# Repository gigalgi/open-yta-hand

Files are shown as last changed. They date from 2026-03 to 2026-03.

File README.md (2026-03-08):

# open-yta-hand

**Underactuated anthropomorphic hand with integrated wrist — 7 DOF per finger, LSTM kinematics, impedance control, ~$8 per finger.**






---

> *Yta* — "hand" in Muisca, the language of the pre-Columbian Chibcha civilization of the Colombian highlands.

---

## Overview

Open-Yta-Hand is a monolithic anthropomorphic robotic hand. The hand is modular:
five UMoBIC fingers assembled into a palm bracket, each finger independent and
using the same tendon coupling and actuation approach. Every joint in the finger
is a UMoBIC compliant revolute unit — printed in one session, no assembly of
structural parts. The control stack runs from ArUco motion capture data collection
through LSTM-based inverse kinematics to real-time impedance control on Arduino.

```
motion_capture/ → dataset/ → lstm/ → firmware/ → hardware
                                  ↓
                          simulation/mujoco
                                  ↓
                              rl/
```

<div align="center">
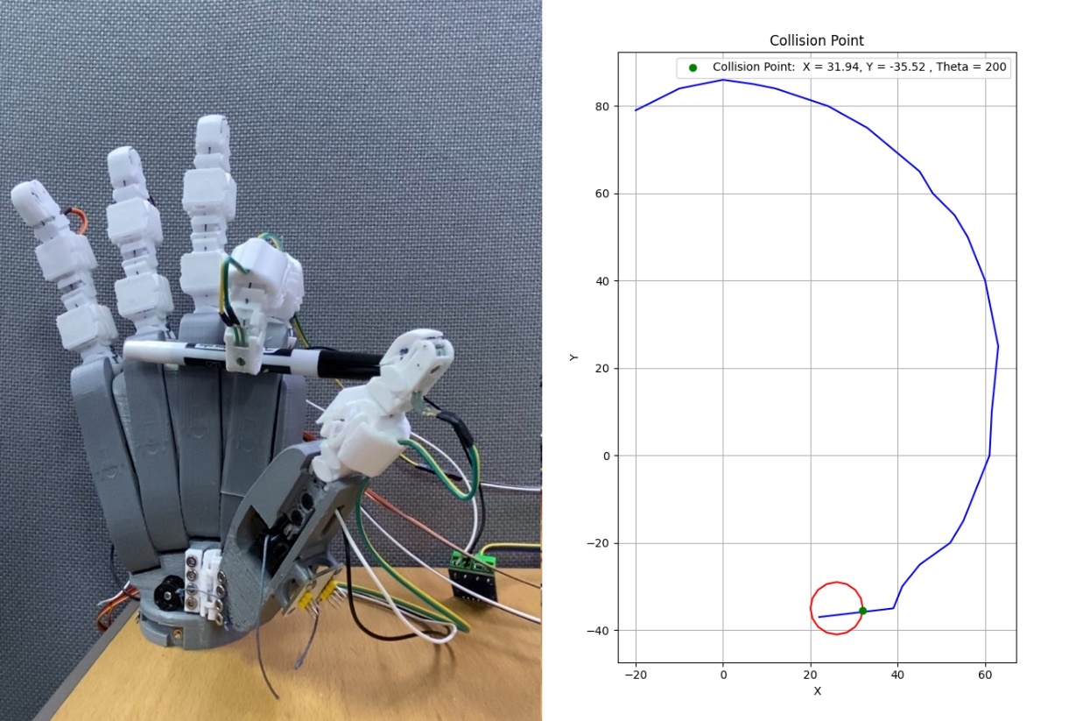
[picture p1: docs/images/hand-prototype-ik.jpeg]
Physical hand prototype
  
  <br><em>Physical prototype and computed fingertip trajectory with grasp collision point.</em>
</div>

---

## Repository Structure

```
open-yta-hand/
├── cad/
│   └── stl/
│   │    ├── arm/
│   │    │   ├── shoulder/
│   │    │   └── elbow/
│   │    ├── hand/
│   │    │   ├── finger/
│   │    │   ├── palm/
│   │    │   └── thumb/
│   │    └── wrist/
│   │
│   └── step/ full assembly
│       
│
├── motion_capture/          ArUco data collection, preprocessing
│   ├── dataset_collection.py
│   ├── marker_detection.py
│   ├── marker_creator.py
│   ├── serial_logger.py
│   ├── data_cleaning.py
│   └── data_slicing.py
│
├── dataset/                 Collected motion capture data
│   ├── finger_trajectory_dataset.csv
│   ├── train_data.csv
│   └── test_data.csv
│
├── kinematics/              Analytical and simulation models
│   ├── forward_kinematics.py
│   ├── continuum_ik.py
│   ├── optimization_ik.py
│   ├── finger_simulator.py
│   └── trajectory_simplifier.py
│
├── lstm/                    LSTM joint angle observer
│   ├── model.py
│   ├── train.py
│   ├── predict.py
│   └── weights/
│       └── lstm_inverse_kinematics.pth
│
├── simulation/
│   ├── mujoco/              MuJoCo model — exact physics, ground truth
│   │   ├── mjmodel.xml
│   │   ├── objects/pen.xml
│   │   └── meshes/
│   └── isaac_sim/           Isaac Sim simulation (in development)
│
├── rl/                      Reinforcement learning (SAC)
│   ├── env.py
│   ├── train.py
│   ├── play.py
│   ├── workspace_vis.py
│   └── weights/
│
├── firmware/
│   └── impedance_control/
│       └── impedance_control.ino
│
├── ros2_ws/                 ROS2 control package (in development)
│   └── src/umobic_finger/
│
├── docs/images/
├── requirements.txt
└── .gitignore
```

---

## Hardware

### The Finger — 208 mm, 7 DOF

Each finger is a single PETG print with all joints, pulleys, and skin modules in one session. Two motors drive the entire structure:

- **Motor 1 (JA12-N20, 1:150 + 2:1 bevel gear)** — flexion/extension via main cable routed through all phalanges
- **Motor 2 (MG90S servo)** — abduction/adduction via 90°-offset MCP joint
- **Cam-follower differential** — passively decouples DIP joint for precision tip grasps

<div align="center">
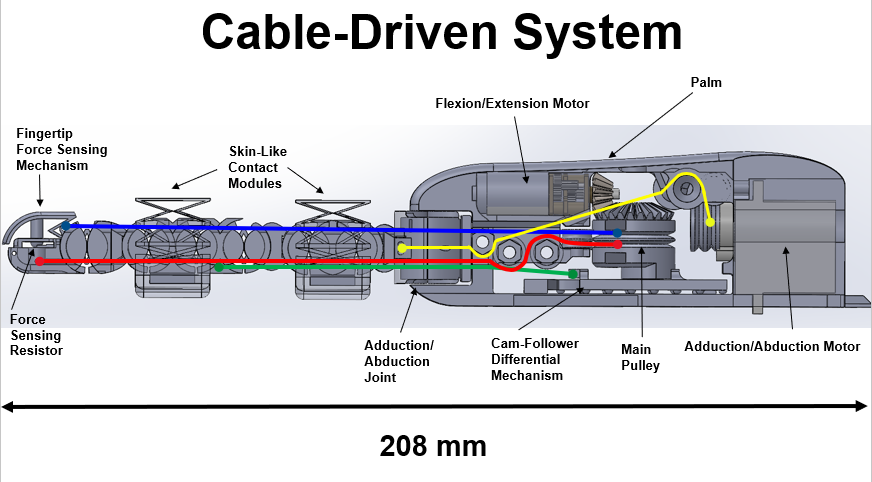
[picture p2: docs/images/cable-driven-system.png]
Cable-driven system
  
  <br><em>Internal mechanism: FSR-400 force sensing, skin modules, adduction joint, cam-follower differential, main pulley — 208 mm total.</em>
</div>

**Specs:**

| Parameter | Value |
|---|---|
| DOF per finger | 7 (6 flexion + 1 abduction) |
| Length | 208 mm |
| Weight | ~85 g |
| Cost (incl. actuators + sensors) | ~$8 USD |
| Material | PETG |
| Fabrication | Single FDM session (Creality Ender 3 V2 Neo) |
| Encoder | AS5600 magnetic (12-bit, I²C) |
| Force sensor | FSR-400 (0–10 N via fingertip transmission) |
| Microcontroller | Arduino (ATmega or equivalent) |

---

## Kinematics Pipeline

The cable-driven underactuated design couples all 6 flexion joints through a single tendon. Cable elasticity, friction, and the passive differential make the relationship between motor angle θ and fingertip position (x, y) highly nonlinear — impossible to capture analytically at high angles.

### 1. Forward Kinematics (analytical)

When the main pulley with radius r_p rotates by θ, the cable change distributes across n rolling-contact joints:

```
φᵢ = (r_p · θ) / (rᵢ · n)
```

The 2D simulator (`kinematics/finger_simulator.py`) visualizes this interactively — use arrow keys to rotate the pulley and watch all joints respond.

### 2. Continuum IK

Models the finger as a single-section continuum robot, computing bending angle and arc length from chord vector. Accurate at low angles, diverges at high angles due to unmodeled cable elasticity.

### 3. LSTM Joint Angle Observer

Selected over FNN, RNN, CNN, and Transformer after systematic comparison (see thesis Table 4.1). LSTM scored highest on temporal dependency handling, nonlinearity modeling, and robustness to noise — all critical for cable-driven compliant systems.

**Architecture:**
```
Input (x, y) → LSTM(64 hidden) → Linear → θ_motor
```

**Training:**
- Dataset: 4 runs × 2000 samples = ~8000 points
- Split: 75% train / 15% test
- Optimizer: Adam, lr=0.01, weight_decay=0.01
- Scheduler: lr × 0.5 every 10 epochs
- Epochs: 100, batch size: 32

**Results:**

| Metric | Value |
|---|---|
| Training loss | 0.6608 |
| Validation loss | 0.6884 |
| R² | **0.9998** |
| MSE | 0.6684 |
| RMSE | 0.8297 |
| MAE | 0.4291 |

---

## Motion Capture Setup

Data collection used a Logitech C270 camera, OpenCV, and ArUco markers to track fingertip (x, y, φ) while an AS5600 encoder measured pulley angle θ over serial.

<div align="center">
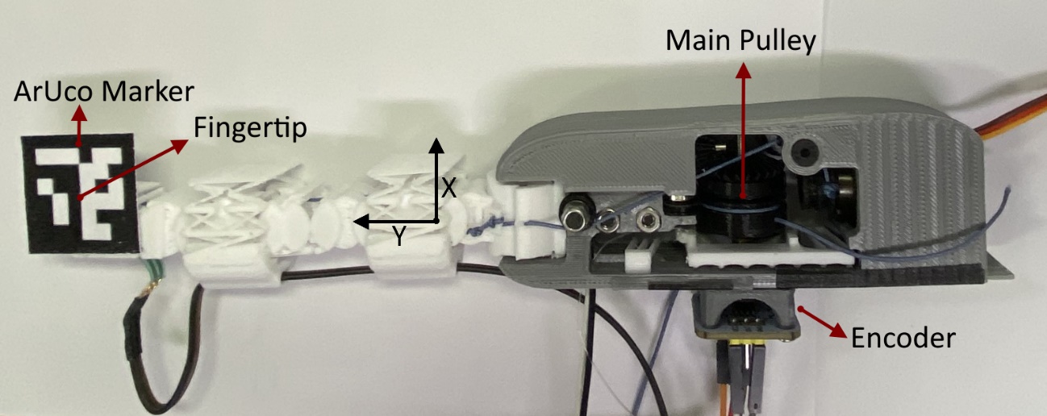
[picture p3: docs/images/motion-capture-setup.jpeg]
Motion capture setup
  
  <br><em>ArUco marker at fingertip, encoder at base. 500 samples per run × 4 runs.</em>
</div>

```bash
# 1. Print markers
python motion_capture/marker_creator.py

# 2. Collect data (camera port + Arduino serial port)
python motion_capture/dataset_collection.py

# 3. Log Arduino encoder output
python motion_capture/serial_logger.py

# 4. Clean and normalize
python motion_capture/data_cleaning.py

# 5. Split train/test
python motion_capture/data_slicing.py
```

---

## LSTM Training & Inference

```bash
# Train from scratch
cd lstm/
python train.py

# Run inference on new fingertip positions
python predict.py

# Monitor training
tensorboard --logdir logs/
```

**Quickstart inference:**
```python
from lstm.model import load_model
import torch

model = load_model("lstm/weights/lstm_inverse_kinematics.pth")

# Predict motor angle for fingertip at (31.94, -35.52)
x = torch.tensor([[[31.94, -35.52]]], dtype=torch.float32)
with torch.no_grad():
    theta = model(x).item()
print(f"θ_motor = {theta:.1f}°")  # → ~200°
```

---

## MuJoCo Simulation

The MuJoCo model represents all 9 joints with tendon equality constraints that
replicate the physical cable transmission exactly. Two position actuators drive
the structure at 500 Hz.

```bash
conda activate mujoco-env
python -m mujoco.viewer simulation/mujoco/mjmodel.xml
```

See `simulation/mujoco/README.md` for full model documentation.

---

## Reinforcement Learning

SAC policy trained entirely in MuJoCo simulation.
Observation: `[qpos(9), fingertip(3), target(3)]`.
Action: `[servo, motor]` normalized to `[-1, 1]`.

```bash
conda activate mujoco-env

# Train
python rl/train.py --steps 300000

# Watch training with viewer
python rl/train.py --steps 50000 --render

# Run trained policy
python rl/play.py --model rl/weights/best.zip

# Visualize reachable workspace
python rl/workspace_vis.py --steps 10000
```

---

## Impedance Control (Arduino)

`firmware/impedance_control/impedance_control.ino` implements a variable spring-mass-damper controller running at 100 Hz:

```
τ = K·(θ_desired − θ) + B·(−θ̇) + M·(−θ̈) − F_contact
```

**Key design decisions:**
- **Variable K and B** — stiffness halves when position error < 5°, damping reduces near zero velocity
- **Kalman filters** on velocity, acceleration, and contact force independently
- **SolidWorks-derived inertia** — M = 451.27 × 10⁻⁹ kg·m² from CAD model
- **Self-calibration on boot** — 30-sample FSR-400 offset averaging

| Parameter | Value |
|---|---|
| Stiffness K | 6.25 N/deg |
| Damping B | 2.25 N·s/deg |
| Inertia M | 451.27 × 10⁻⁹ kg·m² |
| Sample rate | 100 Hz |
| Encoder | AS5600, 12-bit |
| Force sensor | FSR-400, max 1000g |

---

## Grasping Results

Tested across 12+ object types including rigid (Rubik's cube, Pringles can), soft (sponge), and tool-shaped (marker, pliers) objects.

<div align="center">
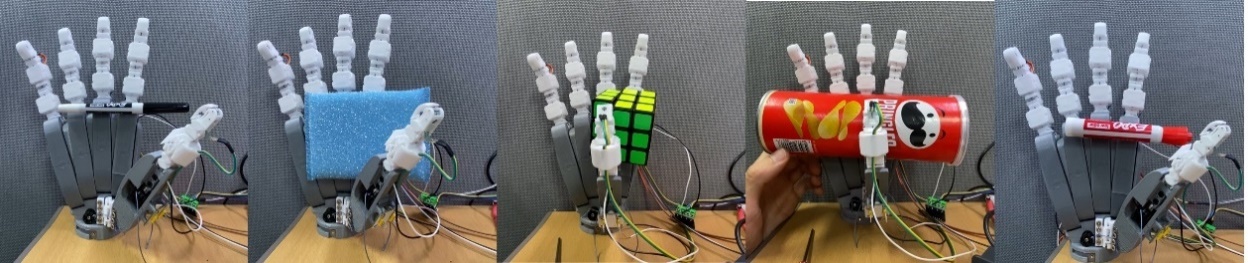
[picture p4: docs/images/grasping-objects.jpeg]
Grasping results
  
  <br><em>Underactuated grasps: marker, sponge, Rubik's cube, Pringles can, tip grasp.</em>
</div>

<div align="center">
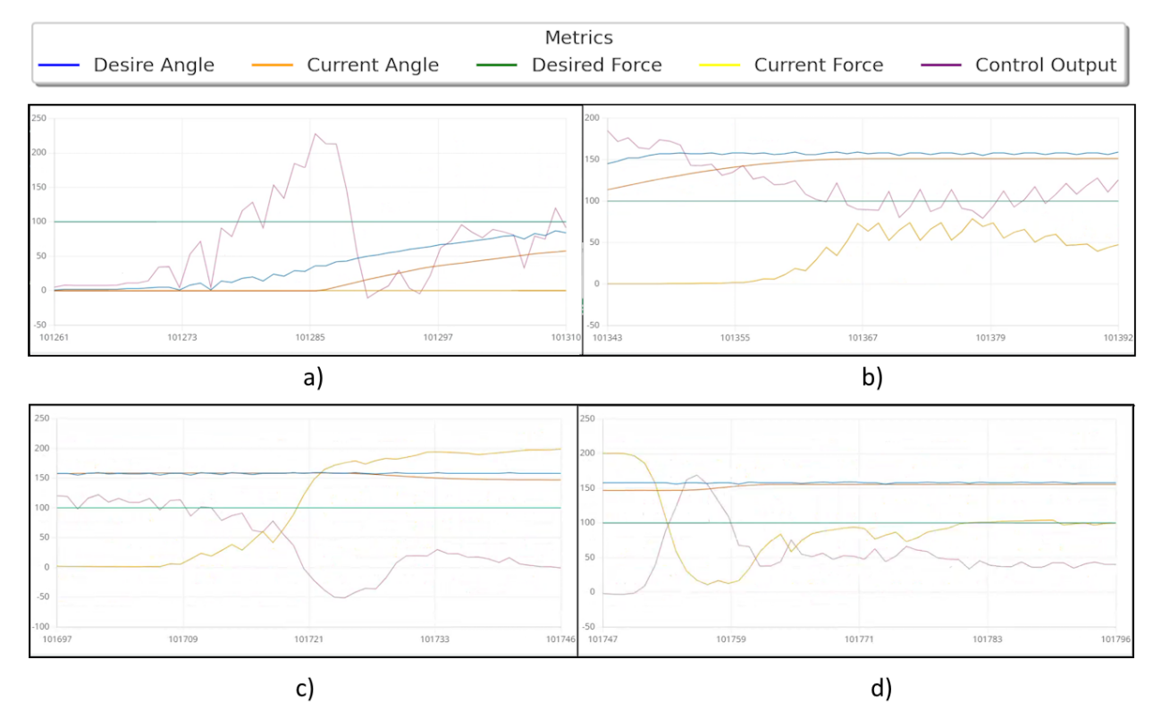
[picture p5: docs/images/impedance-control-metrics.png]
Impedance metrics
  
  <br><em>Impedance control metrics across four grasping trials.</em>
</div>

---

## 3D Printing

The `cad/stl/` folder contains STL files for the complete physical assembly:
finger, palm, thumb, wrist, shoulder and elbow.
Full mechanical context and assembly diagrams are in the thesis.

### Material

**PETG is strongly recommended over PLA.** PETG has higher elasticity which
gives more life cycles at the flexible joint layers before fatigue failure.
PLA is stiffer and will crack at the flex zones sooner under repeated actuation.

- Layer height: 0.2 mm is sufficient for all parts
- Supports: use tree-type supports — easier to remove from narrow flex zones

### Print orientation — critical

**Layer orientation is the most important parameter for this design.**
Flexible layers must be oriented so that layer lines run perpendicular to
the direction of motion. Parallel layer lines cause delamination under
repeated bending. Most parts use 2D geometry that grows vertically for
this reason. Print them standing upright as oriented in the STL files.

### Wrist — special handling required

> ⚠️ **Warning — experimental design**
>
> The wrist joint uses a 3D configuration unlike the 2D geometry of the
> finger and other joints. Correct layer orientation cannot be achieved
> for all surfaces in a single print. Parts printed as one piece have a
> higher risk of cracking at the flex zone under load.
>
> **Recommended approach:** print the wrist in two separate halves,
> keeping the critical flex surface correctly oriented in each half,
> then bond with cyanoacrylate or epoxy.

The elbow and shoulder follow the same 2D vertical geometry as the finger
and can be printed as single pieces. All arm joints should be considered
experimental — long-term fatigue behavior under repeated actuation has
not been fully characterized.

---

## In Development

**ROS2 control and simulation bridges** — architecture and implementation
are defined. MuJoCo bridge, Isaac Sim integration, and policy node are
implemented but require further debugging and testing.
See `ros2_ws/` and `simulation/isaac_sim/`.

**open-yta-hand-mk2** — a next-generation hand currently in development.
It follows the same design philosophy as the monolithic anthropomorphic hand
project and the UMoBIC finger. The mk2 builds on this foundation adding
better features for skin, force and shape sensing and more independent
degrees of freedom for easier control.

---

## Getting Started

```bash
git clone https://github.com/yourusername/open-yta-hand
cd open-yta-hand
pip install -r requirements.txt

# Interactive 2D finger simulator
python kinematics/finger_simulator.py

# MuJoCo simulation
conda activate mujoco-env
python -m mujoco.viewer simulation/mujoco/mjmodel.xml

# LSTM inference
python lstm/predict.py
```

---

## Publications

**ICCAS 2024**
> *Design of a Modular Anthropomorphic Hand with Integrated Monolithic Compliant Fingers and Wrist Joint*
> Gilberto Galvis Giraldo, Arpan Ghosh, Tae-Yong Kuc. [[Paper]](https://ieeexplore.ieee.org/document/10773068)

**Master's Thesis — SKKU 2024**
> *Monolithic Robotics with Cognitive AI: A Compliant Mechanism-Based Anthropomorphic Arm Design for Semantic Autonomous Manipulation*
> Gilberto Galvis Giraldo
> [[Full text]](https://dcollection.skku.edu/srch/srchDetail/000000181091?localeParam=en)

**Technical Report — 2023**
> *UMoBIC-Finger: A FACT-Based Compliant Revolute Joint for Monolithic Robotic Fingers*
> [[monolithic-robotics repository]](https://github.com/gigalgi/monolithic-robotics)

---

## Related Repositories

| Repository | Description |
|---|---|
| [monolithic-robotics](https://github.com/yourusername/monolithic-robotics) | Design framework — UMoBIC joint, FACT methodology, technical report |

---

## Author

**Gilberto Galvis Giraldo**
M.Sc. Electrical and Computer Engineering — Sungkyunkwan University, South Korea

---

## License

Apache License 2.0 — see [LICENSE](LICENSE) for details.

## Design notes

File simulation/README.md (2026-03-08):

# simulation/

Physics simulation files for the UMoBIC-Finger.
Two simulators, each with its own folder and model file.

```
simulation/
├── mujoco/
│   ├── mjmodel.xml        MuJoCo model — exact physics, ground truth
│   └── objects/pen.xml    pen object included by mjmodel.xml
│   └── meshes/            STL files shared by both simulators
└── isaac_sim/
    ├── finger_isaac.urdf  Isaac Sim model
    ├── isaac_play.py      standalone viewer — sliders, no ROS2
    └── isaac_bridge.py    ROS2 controlled — same topics as mujoco_bridge
```

---

## mujoco/

The ground truth model. Used by the RL training pipeline and the
ROS2 MuJoCo bridge.

`mjmodel.xml` defines:
- Exact rolling-contact joint kinematics via tendon equality constraints
- Position actuators for servo and motor (`joint_s_pos`, `joint_m_pos`)
- Contact capsules on each phalanx for pen interaction
- A `fingertip` site at the tip of the distal phalanx — used by
  `rl/env.py` and `ros2_ws/mujoco_bridge.py` to get exact fingertip
  world position without any FK computation

Run standalone (no ROS2):
```bash
python -m mujoco.viewer simulation/mujoco/mjmodel.xml
```

Run via ROS2:
```bash
ros2 launch umobic_finger sim.launch.py
```

Run via RL training:
```bash
python rl/train.py
python rl/play.py --model rl/weights/best.zip
```

---

## isaac_sim/

Isaac Sim simulation files. Two independent modes — use whichever
fits what you are doing.

### Standalone (no ROS2)

Quick visual testing. No build step. Just run.

```bash
python simulation/isaac_sim/isaac_play.py
```

A GUI panel opens with two sliders:

| Slider | Range | Effect |
|---|---|---|
| Servo | -0.3 to 0.3 rad | Abduction — side to side |
| Motor | -0.3 to 3.14 rad | Flexion — open to closed |

### ROS2 controlled

Isaac Sim runs the physics. All ROS2 nodes connect unchanged via
Isaac Sim's built-in ROS2 bridge extension.

One-time setup:
```
Isaac Sim → Window → Extensions → search "ROS2 Bridge" → enable + autoload
```

Run:
```bash
# Terminal 1
python simulation/isaac_sim/isaac_bridge.py

# Terminal 2 — identical to MuJoCo workflow
ros2 run umobic_finger finger_teleop.py
ros2 param set /finger_teleop motor 1.5
```

`finger_teleop.py` and `policy_node.py` work with both bridges.
The ROS2 nodes cannot tell which simulator is running.

---

## Why two simulators

| | MuJoCo | Isaac Sim |
|---|---|---|
| Model file | `mjmodel.xml` | `finger_isaac.urdf` |
| Physics | MuJoCo (exact tendons) | PhysX |
| Fingertip position | `<site>` tag | `fingertip_site` fixed link + USD FK |
| Mimic joints | tendon equality constraints | applied manually in Python |
| ROS2 bridge | `mujoco_bridge.py` (in ros2_ws) | `isaac_bridge.py` (here) |
| Use for | RL training, full pipeline, hardware prep | visual testing, demos |
| Requires | any machine | Isaac Sim + RTX GPU |

---

## Model files are not interchangeable

Each simulator has its own model file optimised for its own format
and capabilities. They share the same STL geometry from `meshes/`
but are otherwise independent.

```
mjmodel.xml           → loaded only by MuJoCo
finger_isaac.urdf     → loaded only by Isaac Sim
ros2_ws/urdf/finger.urdf  → loaded only by RViz / robot_state_publisher
```

Ground truth kinematics always live in `mjmodel.xml`.
The URDF files are approximations suitable for visualization.

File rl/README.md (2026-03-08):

# UMoBIC-Finger — RL Training (`rl/`)

Reinforcement learning pipeline for training a fingertip positioning policy
on the UMoBIC-Finger **in simulation only**. No hardware connection needed.

---

## Position in the full system

```
rl/train.py          trains the policy in MuJoCo simulation
      ↓
rl/play.py           interactive: type a target, finger moves and holds
      ↓
(future) pipeline.py → predict.py → SerialBridge → Arduino
```

The RL policy learns the relationship between **servo + motor commands** and
**fingertip position in 3D space**. Once trained, give it any reachable target
coordinate and it drives the finger there and holds that position.

---

## File structure

```
rl/
├── config.py            All hyperparameters and paths — edit here only
├── env.py               Gymnasium environment wrapping mjmodel.xml
├── train.py             SAC training + checkpointing + optional live viewer
├── play.py              Interactive viewer: type target → finger moves → holds
├── workspace_vis.py     3D plot of the real reachable fingertip workspace
├── requirements.txt     Python dependencies
├── weights/             Saved checkpoints (created on first run)
└── logs/                TensorBoard logs (created on first run)
```

---

## Quick start

### 1. Install dependencies

```bash
pip install -r rl/requirements.txt
```

### 2. Train

```bash
# Headless — full speed (recommended for full runs)
python rl/train.py

# With live MuJoCo viewer — ~30% slower, use for debugging behavior
python rl/train.py --render

# Short debug run — watch ~15 seconds of sim, then stop
python rl/train.py --render --steps 5000

# Resume from checkpoint
python rl/train.py --resume rl/weights/ckpt_100000.zip

# Custom step budget
python rl/train.py --steps 500000
```

Monitor training in a second terminal:

```bash
tensorboard --logdir rl/logs/SAC_1
```

The best model by mean reward is always saved at `rl/weights/best.zip`.

#### What `--steps` means

Each step = one action applied to the simulation (5 physics substeps at 0.002s each = 0.01s of simulated time).

```
5,000 steps  ≈  50 s simulated  ≈  ~2 min wall-clock  (with --render)
50,000 steps ≈   8 min simulated ≈  ~15 min wall-clock  (with --render)
300,000 steps ≈  50 min simulated ≈  ~30 min wall-clock  (headless)
```

Each episode is 300 steps (3 seconds of sim). So 300k steps ≈ 1,000 episodes.

#### Recommended debug workflow

```bash
# 1. Confirm viewer opens and finger moves
python rl/train.py --render --steps 5000

# 2. Watch early learning — is reward going up?
python rl/train.py --render --steps 50000

# 3. Full training, no viewer, full speed
python rl/train.py --steps 300000
```

### 3. Visualize the workspace

Before or after training, see where the fingertip can actually reach:

```bash
# Run from anywhere — script resolves its own path
python rl/workspace_vis.py
python rl/workspace_vis.py --steps 10000     # denser plot
python rl/workspace_vis.py --color-by z      # color by height
python rl/workspace_vis.py --color-by time   # color by sweep order
```

The plot shows the real reachable arc plus the pen center and grasp contact
point from `grasp_point_generator.py` — so you can verify the pen sits
inside the fingertip workspace.

#### Why workspace_vis.py lives in `rl/` not `kinematics/`

The workspace shown is the **actual fingertip arc produced by MuJoCo** —
computed by running random actions through `FingerEnv`, not from the
kinematic equations. It is the workspace the RL policy trains on.
It belongs next to the thing it describes. The script uses
`Path(__file__).resolve().parent` to always find `env.py` and `config.py`
regardless of which folder you run it from.

### 4. Play interactively

```bash
python rl/play.py --model rl/weights/best.zip
```

The MuJoCo 3D viewer opens. Type a fingertip target in meters — the finger
moves to that position and **holds it** until you type a new target.
No auto-reset loop.

```
Waiting for target (finger is at home position)...

> 0.022 -0.035 0.100       ← set target (x y z in meters)
  Moving to target...
  dist=28.4 mm  tip=(18.1, -31.2, 96.4) mm
  dist=9.7 mm   tip=(20.8, -33.8, 99.1) mm
  dist=2.1 mm   tip=(21.9, -35.0, 100.1) mm
  Reached! dist=2.1 mm -- holding.

> r                         ← random target from real workspace
> q                         ← quit
```

**Hold behavior:** once the finger reaches the target (dist < 5 mm) or
times out (300 steps), the last motor commands are frozen — the finger
stays in position. Only a new target restarts the policy.

---

## Algorithm — SAC

SAC (Soft Actor-Critic) was chosen over PPO for this system because:

| Criterion | PPO | **SAC** |
|---|---|---|
| Sample efficiency | Low (on-policy) | **High (replay buffer)** |
| Continuous 2-DOF actions | OK | **Excellent** |
| Nonlinear tendon dynamics | Struggles | **Handles well** |
| Training without GPU | Slow | **Faster** |

All hyperparameters with rationale are in `config.py`.

---

## Observation and action spaces

### Observation (15 values)

| Index | Meaning | Unit |
|---|---|---|
| 0–8 | Joint positions: servo, motor, abd, prx×2, int×3, dis | rad |
| 9–11  | Fingertip world position (x, y, z) via `fingertip` site | m |
| 12–14 | Target position (x, y, z) | m |

The fingertip position is tracked via a MuJoCo `<site>` named `fingertip`
placed at the tip of the distal phalanx in `mjmodel.xml`. This is more
accurate than body origin (`xpos`) which points to the joint center.

### Action (2 values)

| Index | Actuator | Normalized | Real range |
|---|---|---|---|
| 0 | `joint_s_pos` — MG90S servo | [-1, 1] | [-0.3, 0.3] rad |
| 1 | `joint_m_pos` — JA12-N20 motor | [-1, 1] | [-0.3, 3.14] rad |

The 7 passive phalanx joints (prx×2, int×3, dis, abd) are **not commanded**.
They follow `joint_motor` automatically via the tendon equality constraints
in `mjmodel.xml`.

---

## Reward

Dense, minimal, interpretable:

```
reward = -distance(fingertip, target)     always on (meters)
       + 1.0                              bonus when dist < 5 mm
```

A random policy scores around **−19**. A well-trained policy scores near **−9**
at 100k steps and approaches **0** by 300k steps.

---

## Why targets are sampled from the real workspace

This is the most important design decision in `env.py`.

The finger is **underactuated** — 2 actuators drive 9 joints through tendons.
Its reachable workspace is a **thin arc in 3D**, not a rectangular bounding box.
If targets were sampled from a box, most would fall outside the arc and the
policy could never reach them. Reward would never improve and training would diverge.

**Solution (in `env.reset()`):**

```
1. Reset sim to home position
2. Run 40 random actions — record where the fingertip actually goes
3. Pick one of those visited positions as the target
   (+ 1 mm Gaussian noise for variety)
4. Reset sim to home again — episode starts from neutral
```

Step 4 is critical. Without the second reset, the episode would start from
wherever the random rollout left the finger — not from home.

Every target is reachable by construction. Use `workspace_vis.py` to see
the shape of this workspace before training.

---

## Key design decisions

**VecNormalize** — Observations are normalized online during training because
`qpos` (rad), `site_xpos` (m), and target (m) live on different scales.
Normalizer stats are saved alongside the model as `*_vecnorm.pkl`.
**Always load both files together** — the model without its normalizer
performs poorly.

**`mujoco.viewer` must be imported explicitly** — `import mujoco` does not
auto-load the viewer submodule. `env.py` imports `import mujoco.viewer`
explicitly. If you see `AttributeError: module 'mujoco' has no attribute 'viewer'`
this import is missing.

**Single callback** — `LogAndSaveCallback` handles logging, checkpointing,
and best-model tracking in one place.

**`set_target()`** — `env.py` exposes this method so `play.py` can inject
new targets at runtime without resetting the episode.

---

## TensorBoard metrics

| Metric | Meaning |
|---|---|
| `eval/mean_reward`  | Mean episode reward (last 50 episodes) |
| `eval/mean_dist_mm` | Mean fingertip–target distance in mm |
| `rollout/ep_rew_mean` | SB3 native episode reward |
| `rollout/ep_len_mean` | Mean episode length (steps) |

Reading the plots:
- `mean_reward` rising from −19 toward 0 = **training is working**
- `mean_dist_mm` falling from ~55 mm toward 5 mm = **finger getting closer**
- S-curve shape on reward = **normal SAC learning curve**
- `ep_len_mean` flat at 300 = finger hasn't converged yet (still exploring)

---

## Changing the workspace

To see where the fingertip actually goes, run:

```bash
python rl/workspace_vis.py --steps 10000
```

Targets are always sampled from the **real reachable arc** (not a config box)
so you do not need to tune `target_x_range` etc. Those config values are
kept as documentation of the approximate workspace bounds but are not used
for sampling.

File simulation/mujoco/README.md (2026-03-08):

# simulation/mujoco/

MuJoCo simulation of the UMoBIC-Finger.

```
mujoco/
├── mjmodel.xml        main model file
├── objects/pen.xml    pen object included by mjmodel.xml
└── meshes/            STL files for all finger links
```

---

## Run standalone

```bash
conda activate mujoco-env
python -m mujoco.viewer simulation/mujoco/mjmodel.xml
```

The viewer opens with the finger at home position.
Click and drag to rotate. Scroll to zoom.
Double-click a body to select it and see its properties.

---

## What mjmodel.xml defines

**Kinematics** — the finger has 2 actuated inputs and 9 joints.
The 7 phalanx joints are coupled to servo and motor via tendon
equality constraints. These are exact rolling-contact kinematics,
not the linear approximation used in the URDF files.

**Actuators** — two position actuators with gain kp = 500:
- `joint_s_pos` — drives `joint_servo` (abduction, MG90S)
- `joint_m_pos` — drives `joint_motor` (flexion, JA12-N20)

**Fingertip site** — a site named `fingertip` is attached to the
distal phalanx at `pos="0 0 -0.012"`. MuJoCo updates its world
position every physics step. Used by the RL environment and the
ROS2 bridge to get exact fingertip position without any FK computation.

**Physics** — timestep 0.002 s (500 Hz). Damping and stiffness tuned
for stable position control at the actuator gains used.

---

## Actuator ranges

| Actuator | Joint | Range | Physical meaning |
|---|---|---|---|
| `joint_s_pos` | `joint_servo` | -0.3 to 0.3 rad | Abduction L/R |
| `joint_m_pos` | `joint_motor` | -0.3 to 3.14 rad | Open to fully closed |

---

## Tendon gear ratios

MuJoCo enforces these via equality constraints every physics step:

```
joint0_abd  =  0.98   × servo
joint1_prx  =  0.2222 × motor
joint2_prx  =  0.2222 × motor
joint3_int  =  0.2222 × motor
joint4_int  =  0.2222 × motor
joint5_int  = -0.2222 × motor   (cam-follower reversal)
joint6_dis  =  0.5333 × motor
```

---

## Used by

```
rl/env.py              loads mjmodel.xml directly for RL training
rl/train.py            trains SAC policy against this model
rl/play.py             runs trained policy in the viewer
ros2_ws/mujoco_bridge  loads mjmodel.xml for ROS2 control
```

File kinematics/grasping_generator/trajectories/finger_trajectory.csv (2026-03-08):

X | Y
-20.0 | 79.0
-19.85 | 79.08
-19.7 | 79.15
-19.55 | 79.23
-19.4 | 79.3
-19.25 | 79.38
-19.1 | 79.45
-18.95 | 79.53
-18.8 | 79.6
-18.65 | 79.68
-18.5 | 79.75
-18.35 | 79.83
-18.2 | 79.9
-18.05 | 79.98
-17.9 | 80.05
-17.75 | 80.13
-17.6 | 80.2
-17.45 | 80.28
-17.3 | 80.35
-17.15 | 80.43
-17.0 | 80.5
-16.85 | 80.58
-16.7 | 80.65
-16.55 | 80.73
-16.4 | 80.8
-16.25 | 80.88
-16.1 | 80.95
-15.95 | 81.03
-15.8 | 81.1
-15.65 | 81.18
-15.5 | 81.25
-15.35 | 81.33
-15.2 | 81.4
-15.05 | 81.48
-14.9 | 81.55
-14.75 | 81.63
-14.6 | 81.7
-14.45 | 81.78
-14.3 | 81.85
-14.15 | 81.93
-14.0 | 82.0
-13.85 | 82.08
-13.7 | 82.15
-13.55 | 82.23
-13.4 | 82.3
-13.25 | 82.38
-13.1 | 82.45
-12.95 | 82.53
-12.8 | 82.6
-12.65 | 82.68
-12.5 | 82.75
-12.35 | 82.83
-12.2 | 82.9
-12.05 | 82.98
-11.9 | 83.05
-11.75 | 83.13
-11.6 | 83.2
-11.45 | 83.28
-11.3 | 83.35
-11.15 | 83.43
-11.0 | 83.5
-10.85 | 83.58
-10.7 | 83.65
-10.55 | 83.73
-10.4 | 83.8
-10.25 | 83.88
-10.1 | 83.95
-9.97 | 84.01
-9.9 | 84.02
-9.82 | 84.04
-9.75 | 84.05
-9.67 | 84.07
-9.6 | 84.08
-9.52 | 84.1
-9.45 | 84.11
-9.37 | 84.13
-9.3 | 84.14
-9.22 | 84.16
-9.15 | 84.17
-9.07 | 84.19
-9.0 | 84.2
-8.92 | 84.22
-8.85 | 84.23
-8.77 | 84.25
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

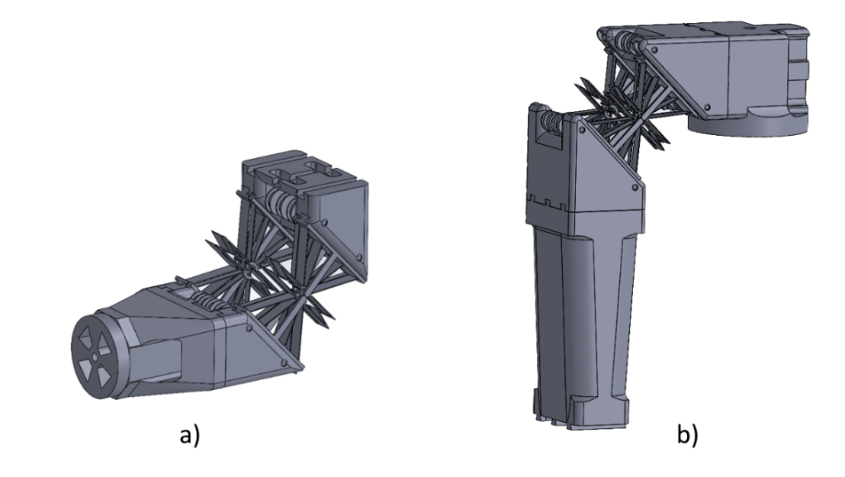
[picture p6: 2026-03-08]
docs/images/wrist-cad.png

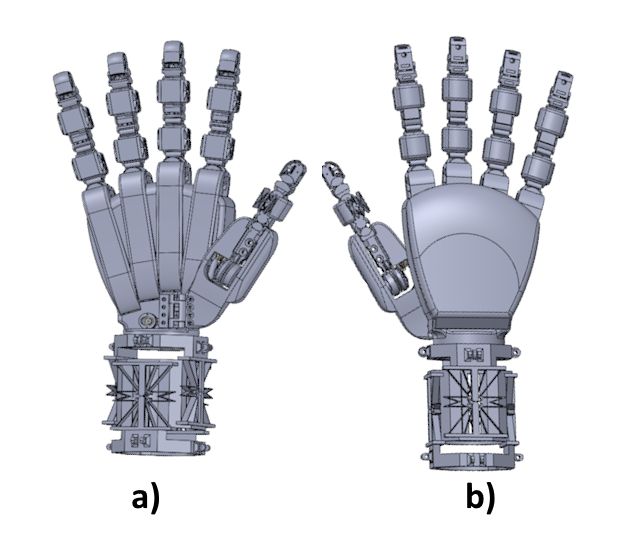
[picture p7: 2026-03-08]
docs/images/hand-cad.png

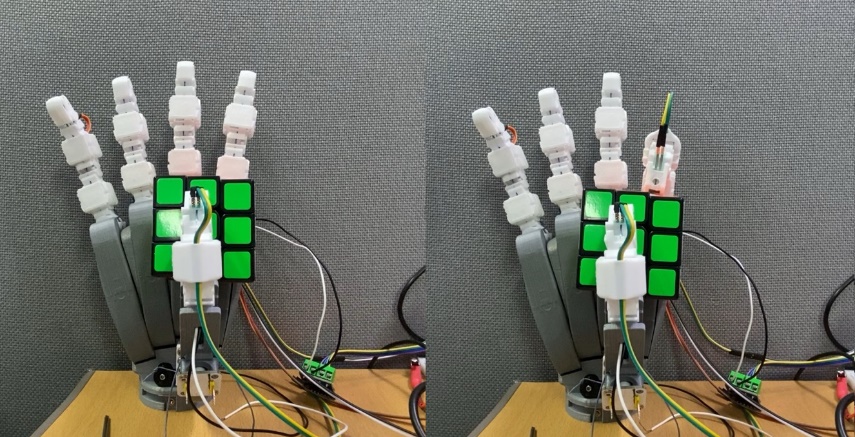
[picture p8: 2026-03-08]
docs/images/impedance-grasping.jpeg

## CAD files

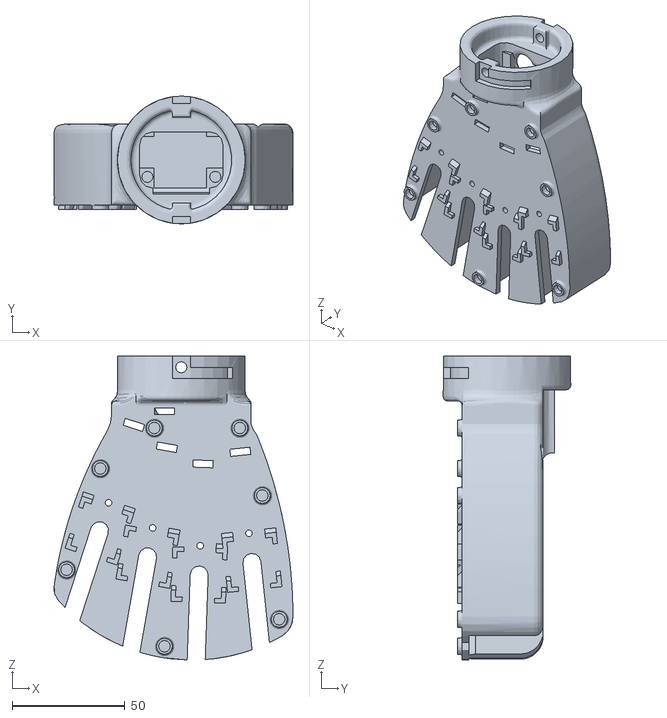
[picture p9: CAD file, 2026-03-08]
cad/stl/hand/palm/hand-main-module.STL
106.2 x 56.8 x 135.1

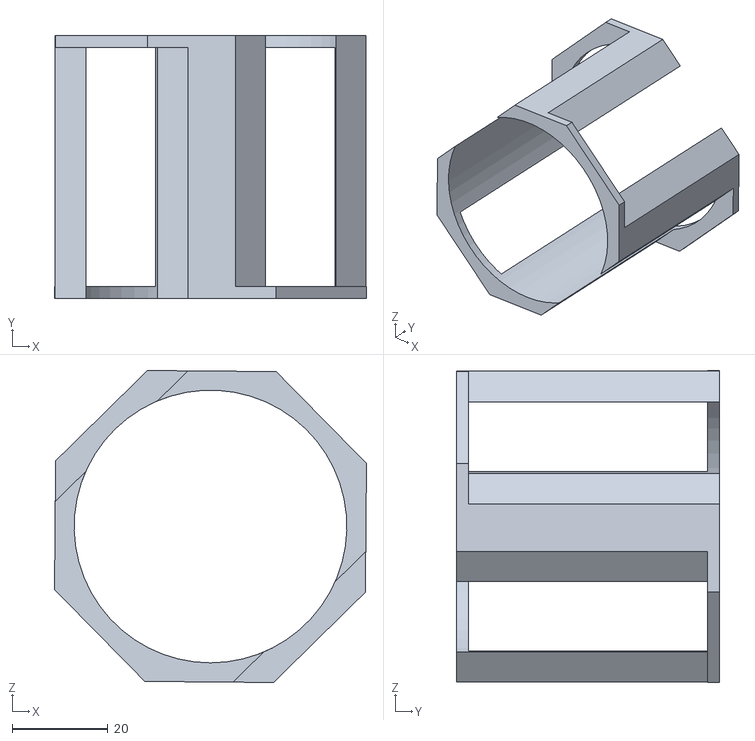
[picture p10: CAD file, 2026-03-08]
cad/stl/wrist/wrist - wrist-main-1-1.STL
65.2 x 55.0 x 65.2

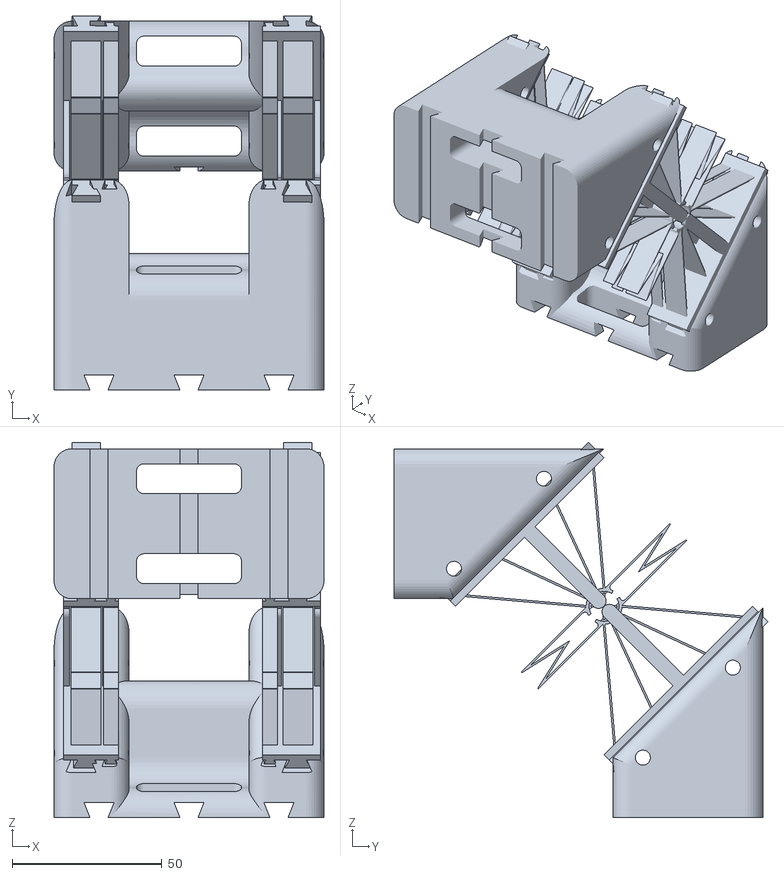
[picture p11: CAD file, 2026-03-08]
cad/stl/arm/elbow/elbow.STL
90.0 x 124.7 x 125.1

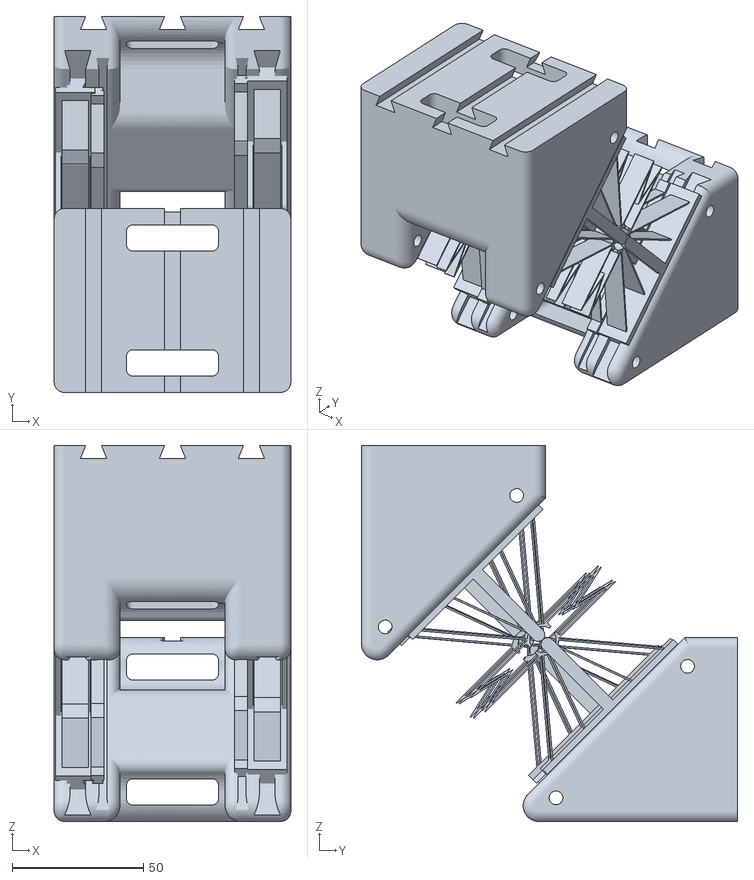
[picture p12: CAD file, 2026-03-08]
cad/stl/arm/shoulder/shoulder.STL
90.0 x 143.0 x 143.0

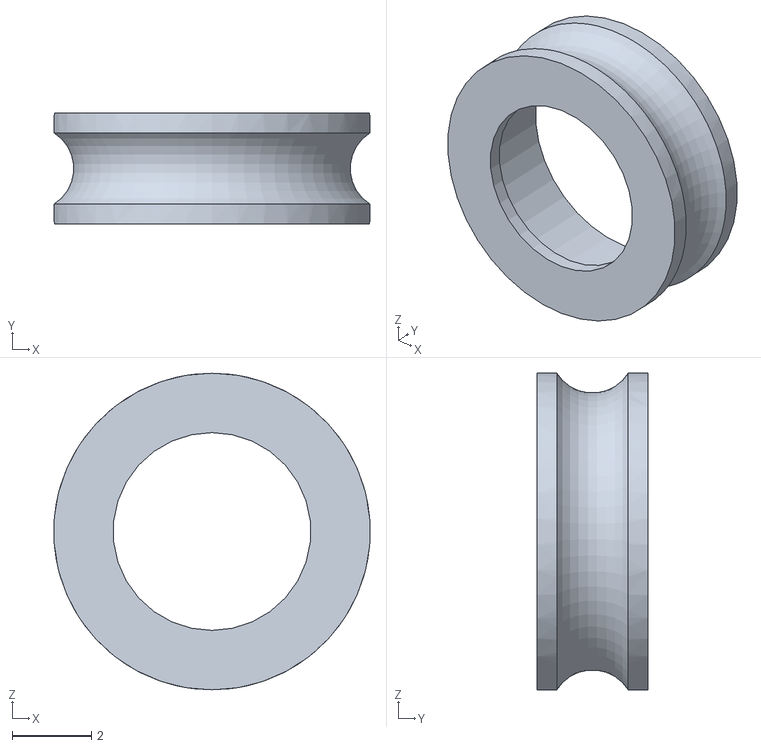
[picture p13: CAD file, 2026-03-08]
cad/stl/hand/finger/pulley-mini.STL
7.99 x 2.80 x 8.00

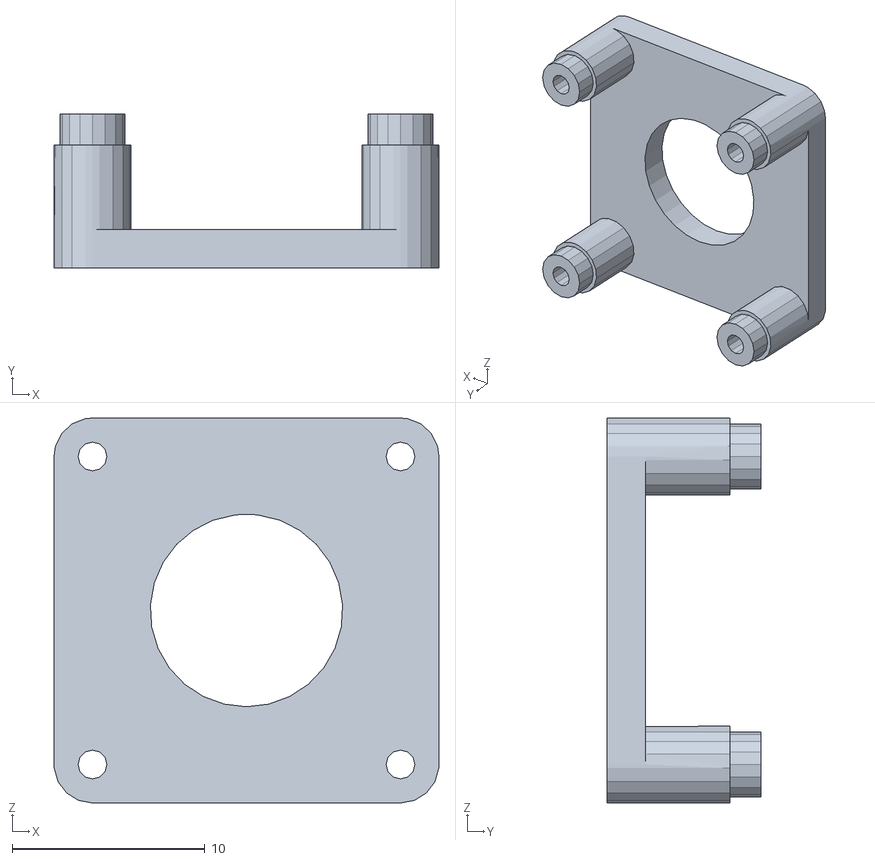
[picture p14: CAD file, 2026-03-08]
cad/stl/hand/thumb/encoder_support-1.STL
20.0 x 8.00 x 20.0

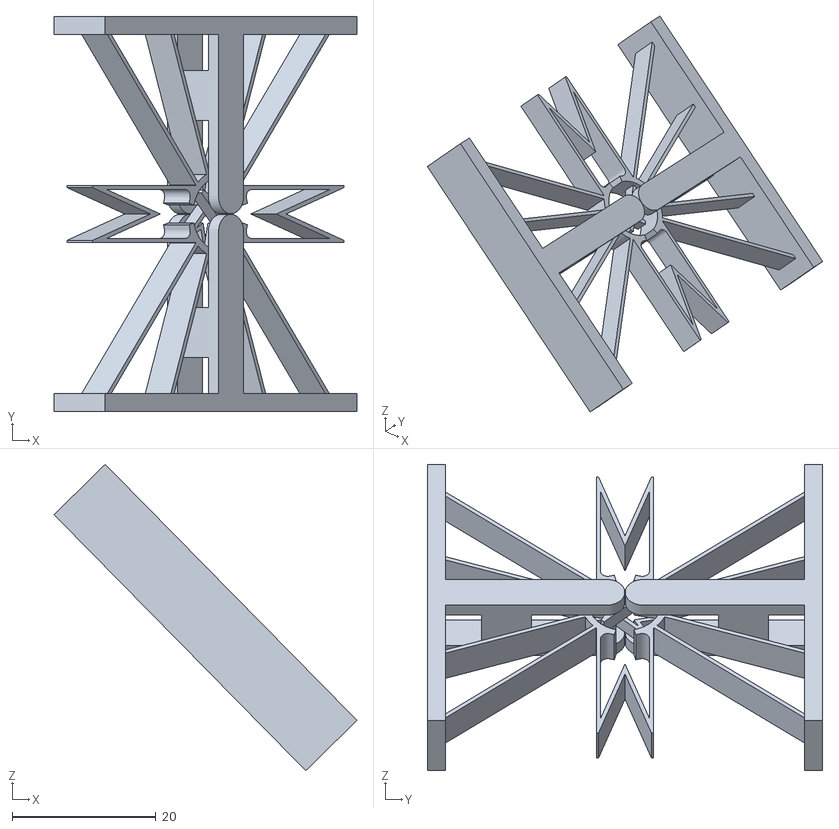
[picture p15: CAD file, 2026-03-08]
cad/stl/wrist/wrist - Part14-5mm-3.STL
42.2 x 55.0 x 42.7

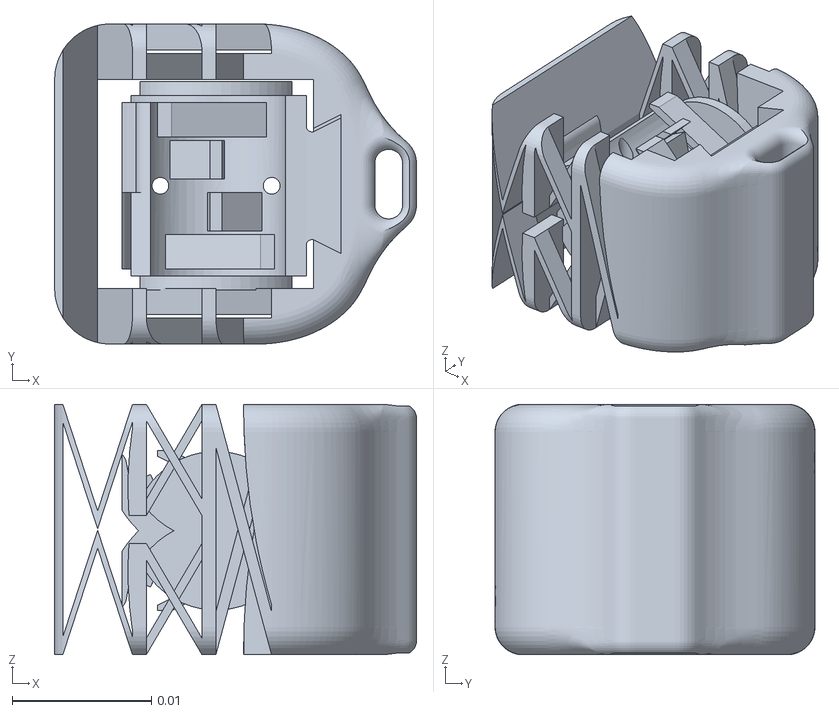
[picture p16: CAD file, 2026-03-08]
simulation/mujoco/meshes/phalanx_link2_int.STL
0.026 x 0.023 x 0.018

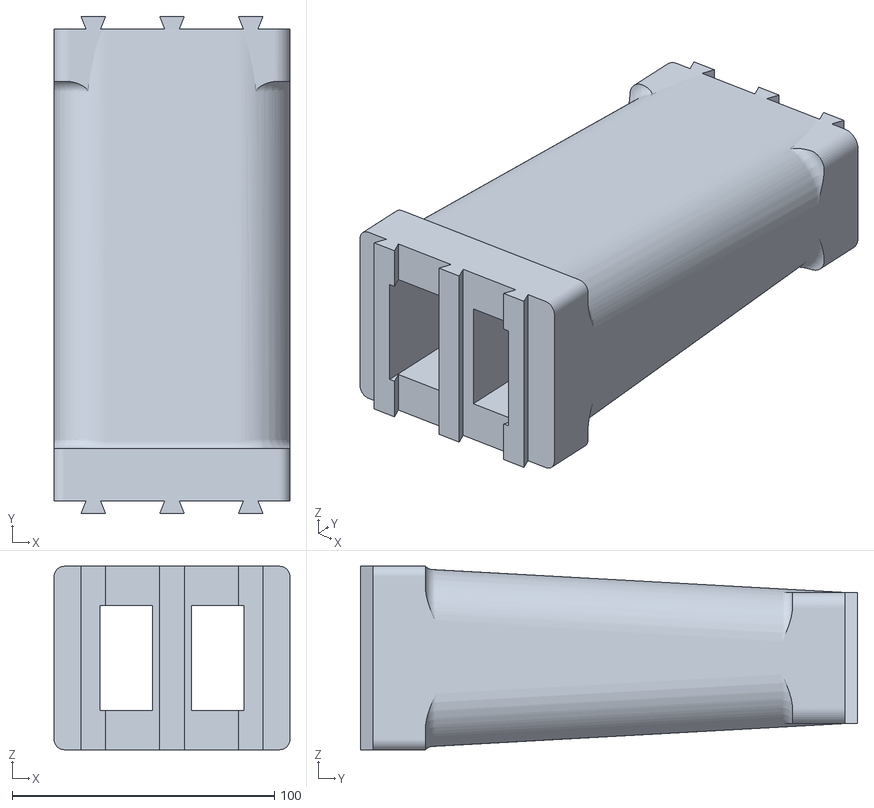
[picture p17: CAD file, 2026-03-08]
cad/stl/arm/elbow/humero.STL
90.0 x 189.6 x 70.0

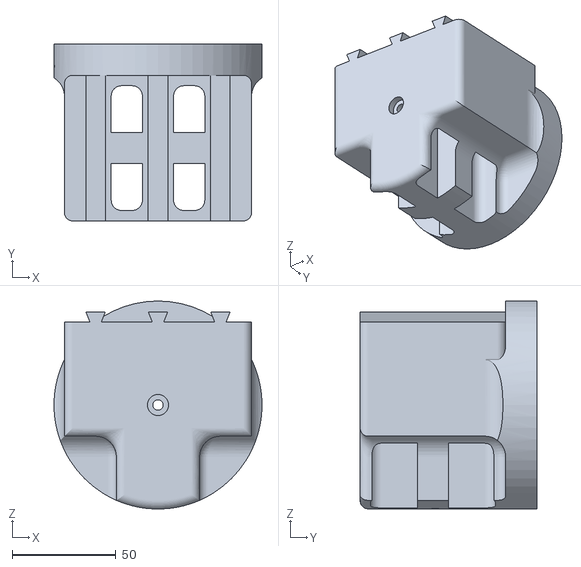
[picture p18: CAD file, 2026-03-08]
cad/stl/arm/shoulder/shoulder_rot.STL
100.0 x 85.0 x 100.0

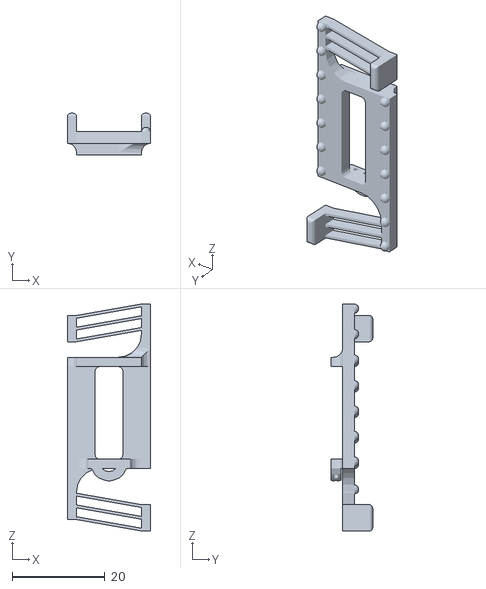
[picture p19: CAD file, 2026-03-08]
cad/stl/hand/finger/cam-follower-2.STL
18.0 x 9.00 x 49.0

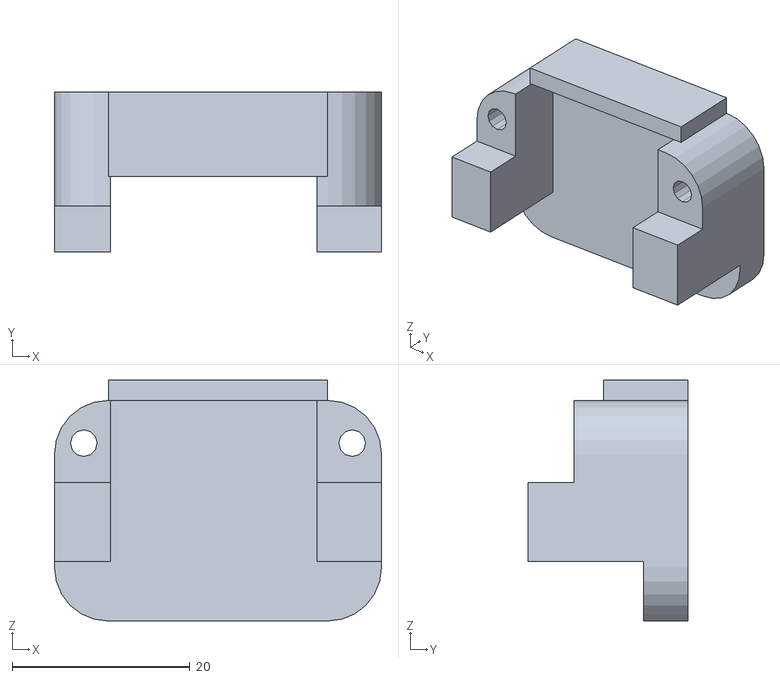
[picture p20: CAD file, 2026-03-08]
cad/stl/hand/palm/servo_palm_support.STL
36.8 x 18.0 x 27.1

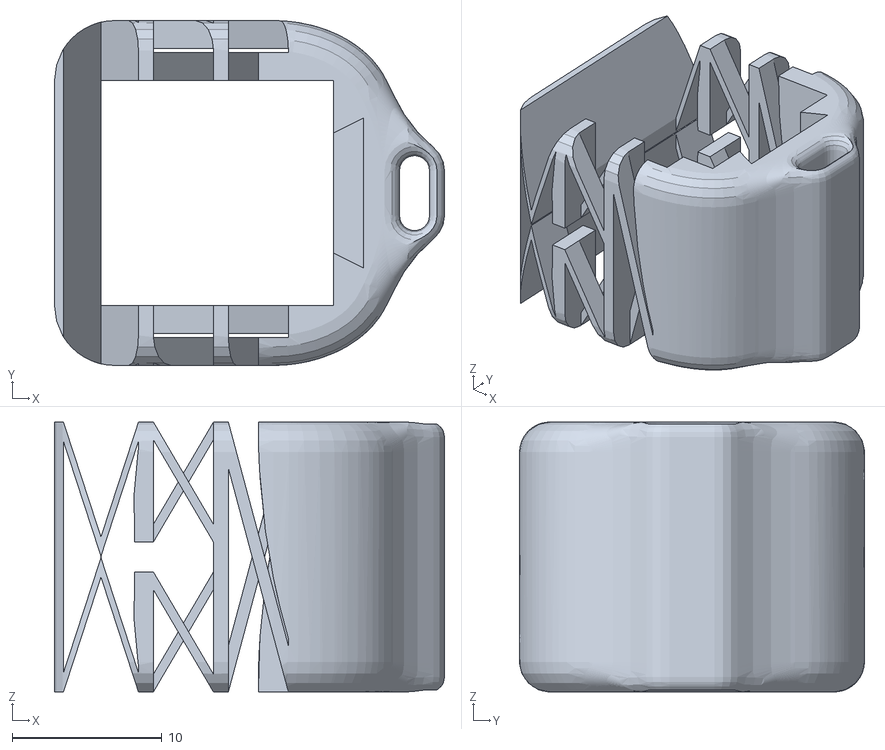
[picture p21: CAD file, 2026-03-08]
cad/stl/hand/thumb/skin8.STL
26.0 x 23.0 x 18.0

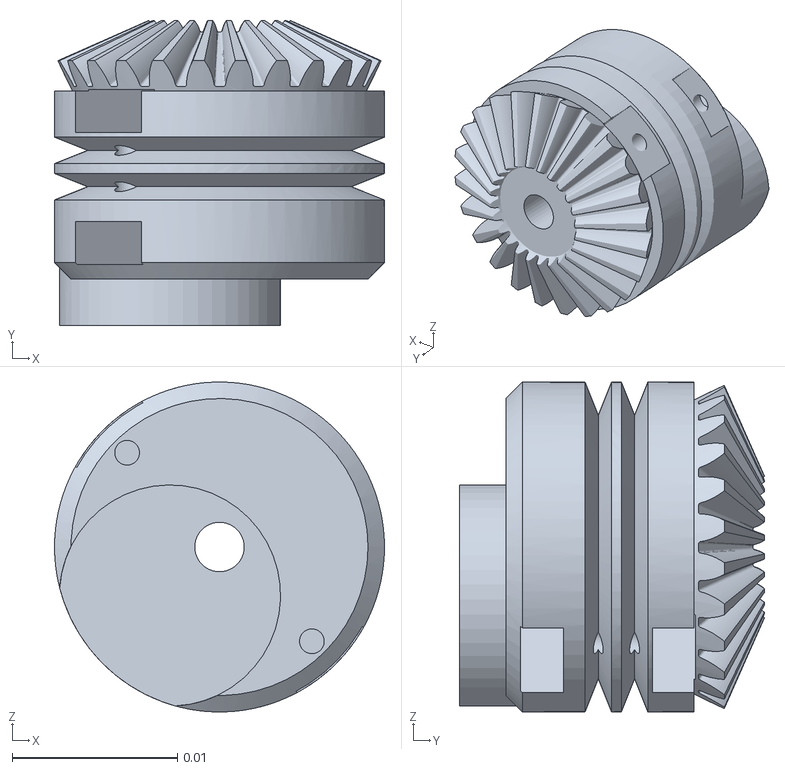
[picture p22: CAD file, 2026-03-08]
simulation/mujoco/meshes/motor_pulley_link.STL
0.02 x 0.0185 x 0.02

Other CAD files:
cad/stl/wrist/wrist - Part14-5mm-2.STL
cad/stl/hand/finger/monolithic_finger.STL
cad/stl/hand/thumb/monolithic_finger_thumb.STL
simulation/mujoco/meshes/palm_link.STL
cad/stl/hand/finger/bavel_gear_pinion.STL
cad/stl/hand/finger/bavel_gear_pulley.STL
cad/stl/hand/finger/finger-palm-module.STL
cad/stl/hand/finger/monolithic_finger_base.STL
cad/stl/hand/finger/pulley-1S.STL
cad/stl/hand/thumb/bavel_gear_pinion.STL
cad/stl/hand/thumb/bavel_gear_pulley_thumb.STL
cad/stl/hand/thumb/thumb-palm.STL
cad/stl/hand/thumb/thumb_opposable_joint.STL
cad/stl/wrist/radi_cubit.STL
cad/stl/wrist/wrist - Part14-5mm-1.STL
cad/stl/wrist/wrist - Part14-5mm-4.STL
cad/stl/wrist/wrist - wrist-support-1-1.STL
cad/stl/wrist/wrist - wrist-support-1-2.STL
cad/stl/wrist/wrist.STL
simulation/mujoco/meshes/phalanx1_link1_abd.STL
simulation/mujoco/meshes/phalanx1_link2_prx.STL
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

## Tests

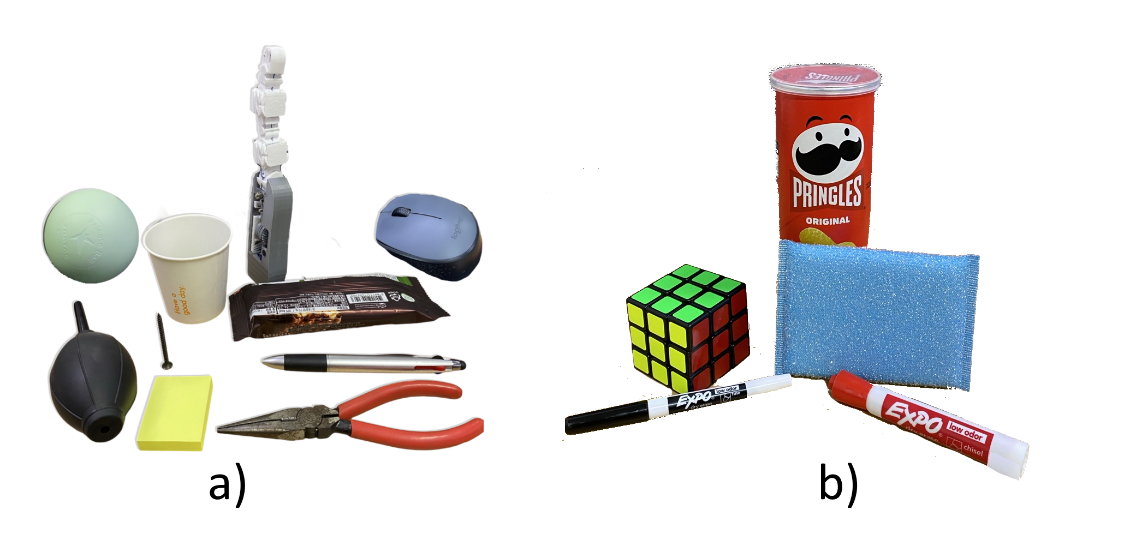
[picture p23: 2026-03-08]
docs/images/test-objects.png

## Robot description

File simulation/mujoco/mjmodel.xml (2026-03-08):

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
<mujoco model="finger_mujoco">

  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
  <compiler angle="radian" meshdir="meshes/" texturedir="texture/"/>

  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
  <option timestep="0.002" iterations="100" apirate="50"/>

  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
  <size njmax="600" nconmax="150" nstack="300000"/>

  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
  <default>
    <joint limited="true" damping="1" frictionloss="0.01" armature=".01"/>
    <position ctrllimited="true" kp="1"/>
  </default>

  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

  <worldbody>
    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
    <light pos="0 0 .6"/>
    <camera name="closeup" pos="0 -.1 .07" xyaxes="1 0 0 0 1 2"/>

    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
    <body name="servo_pulley_link" pos="0.00010005 -0.0199 0.038" quat="0.692275 0.692277 0.144062 0.144061">
      <inertial pos="0 0.0033461 0" quat="0.663108 -0.245537 -0.245537 0.663108" mass="0.00064912" diaginertia="1.7526e-08 1.17082e-08 1.12928e-08"/>
      <joint name="joint_servo" type="hinge" pos="0 0 0" axis="0 1 0" range="-1 1"/>
      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
    </body>

    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
    <body name="motor_pulley_link" pos="0 -0.0065 0.0575" quat="-3.67314e-06 0.999981 -2.2658e-08 -0.00616846">
      <inertial pos="-0.00028931 0.0095592 -0.00028355" quat="0.577387 0.126641 0.408197 0.695674" mass="0.0053624" diaginertia="2.60047e-07 2.57854e-07 2.16879e-07"/>
      <joint name="joint_motor" type="hinge" pos="0 0 0" axis="0 1 0" range="-3.14 3.14"/>
      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
    </body>

    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
    <body name="phalanx1_link1_abd" pos="0.00025 -0.0054079 0.10695" quat="1.34924e-11 -3.67321e-06 1 -3.67321e-06">
      <inertial pos="-5.9722e-05 -0.0084809 -0.0081966" quat="0.0381308 0.680879 -0.0123433 0.731298" mass="0.0025141" diaginertia="9.34887e-08 6.5377e-08 5.99283e-08"/>
      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
      <joint name="joint0_abd" type="hinge" pos="0 0 0" axis="0 1 0" range="-0.7 0.7"/>
      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
      <body name="phalanx_link1_prx" pos="0 -0.0085921 -0.01705" quat="0.707105 0 0 0.707108">
        <inertial pos="0.0031611 0.00033176 -0.0057507" quat="0.00309698 0.713211 -0.0011813 0.700942" mass="0.0059145" diaginertia="5.00815e-07 3.7855e-07 3.54575e-07"/>
        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
        <joint name="joint1_prx" type="hinge" pos="0 0 0" axis="0 1 0" range="-0.7 0.7"/>
        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
        <body name="phalanx1_link2_prx" pos="0 0 -0.0114">
          <inertial pos="0.00029466 0.00025493 -0.0078726" quat="0.513386 0.492274 -0.481524 0.51209" mass="0.002014" diaginertia="5.96415e-08 4.83638e-08 3.38077e-08"/>
          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
          <joint name="joint2_prx" type="hinge" pos="0 0 0" axis="0 1 0" range="-0.7 0.7"/>
          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
          <body name="phalanx_link1_int" pos="0 0 -0.01555">
            <inertial pos="0.00043592 0.00033932 -0.005629" quat="0.466195 0.554663 -0.433837 0.535534" mass="0.0015511" diaginertia="5.62669e-08 4.15694e-08 3.61687e-08"/>
            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
            <joint name="joint3_int" type="hinge" pos="0 0 0" axis="0 1 0" range="-0.7 0.7"/>
            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
            <body name="phalanx_link2_int" pos="0 0 -0.0114">
              <inertial pos="0.0033404 0.00030416 -0.0057723" quat="-0.0167526 0.710991 0.020592 0.7027" mass="0.0057585" diaginertia="4.89393e-07 3.70905e-07 3.49772e-07"/>
              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
              <joint name="joint4_int" type="hinge" pos="0 0 0" axis="0 1 0" range="-0.7 0.7"/>
              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
              <body name="phalanx_link3_int" pos="0 0 -0.0114" quat="-3.67321e-06 1 0 0">
                <inertial pos="9.7987e-05 -0.00025512 0.0076047" quat="0.525574 0.497518 -0.479196 0.496607" mass="0.0019386" diaginertia="6.11345e-08 4.73321e-08 3.33433e-08"/>
                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
                <joint name="joint5_int" type="hinge" pos="0 0 0" axis="0 -1 0" range="-0.7 0.7"/>
                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
                <body name="phalanx_link1_dis" pos="0 0 0.0149" quat="-3.67321e-06 1 0 0">
                  <inertial pos="-0.00010858 0.00025287 -0.0094074" quat="0.711685 0.0099199 0.0104214 0.702351" mass="0.0023104" diaginertia="9.94276e-08 9.5898e-08 7.69994e-08"/>
                  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
                  <joint name="joint6_dis" type="hinge" pos="0 0 0" axis="0 1 0" range="-0.7 0.7"/>
                  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

                </body>
              </body>
            </body>
          </body>
        </body>
      </body>
    </body>

    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

  </worldbody>


  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
  <tendon>

    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
    <fixed name="T_map_j1" range="-1 1">
      <joint joint="joint1_prx" coef="0.036"/>
      <joint joint="joint_motor" coef="-0.008"/>
    </fixed>

    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
    <fixed name="T_map_j2" range="-1 1">
      <joint joint="joint2_prx" coef="0.036"/>
      <joint joint="joint_motor" coef="-0.008"/>
    </fixed>

    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
    <fixed name="T_map_j3" range="-1 1">
      <joint joint="joint3_int" coef="0.036"/>
      <joint joint="joint_motor" coef="-0.008"/>
    </fixed>

    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
    <fixed name="T_map_j4" range="-1 1">
      <joint joint="joint4_int" coef="0.036"/>
      <joint joint="joint_motor" coef="-0.008"/>
    </fixed>

    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
    <fixed name="T_map_j5" range="-1 1">
      <joint joint="joint5_int" coef="0.036"/>
      <joint joint="joint_motor" coef="-0.008"/>
    </fixed>

    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
    <fixed name="T_map_j6" range="-1 1">
      <joint joint="joint6_dis" coef="0.015"/>
      <joint joint="joint_motor" coef="-0.008"/>
    </fixed>

    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
    <fixed name="T_abd_servo" range="0 1">
      <joint joint="joint_servo" coef="-1"/>
      <joint joint="joint0_abd" coef="0.98"/>
    </fixed>

  </tendon>


  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
  <equality>
    <tendon name="E_map_j1" tendon1="T_map_j1"/>
    <tendon name="E_map_j2" tendon1="T_map_j2"/>
    <tendon name="E_map_j3" tendon1="T_map_j3"/>
    <tendon name="E_map_j4" tendon1="T_map_j4"/>
    <tendon name="E_map_j5" tendon1="T_map_j5"/>
    <tendon name="E_map_j6" tendon1="T_map_j6"/>
    <tendon name="E_abd_servo" tendon1="T_abd_servo"/>
  </equality>


  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
  <actuator>
    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
    <position name="joint_s_pos" joint="joint_servo" ctrlrange="-0.3 0.3" kp="400"/>

    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
    <position name="joint_m_pos" joint="joint_motor" ctrlrange="-0.3 3.14" kp="400"/>
  </actuator>

</mujoco>

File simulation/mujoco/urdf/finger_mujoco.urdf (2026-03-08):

<?xml version="1.0" encoding="utf-8"?>
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
<robot name="finger_mujoco">
  <mujoco>
    <compiler meshdir="meshes/" balanceinertia="true" strippath="false"/>
  </mujoco>
  <link name="palm_link">
    <inertial>
      <origin xyz="3.095E-05 -0.018207 0.055563" rpy="0 0 0" />
      <mass value="0.03804" />
      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
    </inertial>
    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
  </link>
  <link name="servo_pulley_link">
    <inertial>
      <origin xyz="1.7347E-18 0.0033461 3.4694E-18" rpy="0 0 0" />
      <mass value="0.00064912" />
      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
    </inertial>
    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
  </link>
  <joint name="joint_servo" type="continuous">
    <origin xyz="0.00010005 -0.0199 0.038" rpy="1.5708 0 0.41034" />
    <parent link="palm_link" />
    <child link="servo_pulley_link" />
    <axis xyz="0 1 0" />
    <limit lower="-1.57" upper="1.57" effort="0" velocity="0" />
  </joint>
  <link name="motor_pulley_link">
    <inertial>
      <origin xyz="-0.00028931 0.0095592 -0.00028355" rpy="0 0 0" />
      <mass value="0.0053624" />
      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
    </inertial>
    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
  </link>
  <joint name="joint_motor" type="continuous">
    <origin xyz="0 -0.0065 0.0575" rpy="3.1416 0.012337 0" />
    <parent link="palm_link" />
    <child link="motor_pulley_link" />
    <axis xyz="0 1 0" />
    <limit lower="-3.12" upper="3.12" effort="0" velocity="0" />
  </joint>
  <link name="phalanx1_link1_abd">
    <inertial>
      <origin xyz="-5.9722E-05 -0.0084809 -0.0081966" rpy="0 0 0" />
      <mass value="0.0025141" />
      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
    </inertial>
    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
  </link>
  <joint name="joint0_abd" type="revolute">
    <origin xyz="0.00025 -0.0054079 0.10695" rpy="3.1416 0 3.1416" />
    <parent link="palm_link" />
    <child link="phalanx1_link1_abd" />
    <axis xyz="0 1 0" />
    <limit lower="-0.7" upper="0.7" effort="0" velocity="0" />
  </joint>
  <link name="phalanx_link1_prx">
    <inertial>
      <origin xyz="0.0031611 0.00033176 -0.0057507" rpy="0 0 0" />
      <mass value="0.0059145" />
      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
    </inertial>
    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
  </link>
  <joint name="joint1_prx" type="revolute">
    <origin xyz="0 -0.0085921 -0.01705" rpy="0 0 1.5708" />
    <parent link="phalanx1_link1_abd" />
    <child link="phalanx_link1_prx" />
    <axis xyz="0 1 0" />
    <limit lower="-0.7" upper="0.7" effort="0" velocity="0" />
  </joint>
  <link name="phalanx1_link2_prx">
    <inertial>
      <origin xyz="0.00029466 0.00025493 -0.0078726" rpy="0 0 0" />
      <mass value="0.002014" />
      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
    </inertial>
    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
  </link>
  <joint name="joint2_prx" type="revolute">
    <origin xyz="0 0 -0.0114" rpy="0 0 0" />
    <parent link="phalanx_link1_prx" />
    <child link="phalanx1_link2_prx" />
    <axis xyz="0 1 0" />
    <limit lower="-0.7" upper="0.7" effort="0" velocity="0" />
  </joint>
  <link name="phalanx_link1_int">
    <inertial>
      <origin xyz="0.00043592 0.00033932 -0.005629" rpy="0 0 0" />
      <mass value="0.0015511" />
      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
    </inertial>
    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
  </link>
  <joint name="joint3_int" type="revolute">
    <origin xyz="0 0 -0.01555" rpy="0 0 0" />
    <parent link="phalanx1_link2_prx" />
    <child link="phalanx_link1_int" />
    <axis xyz="0 1 0" />
    <limit lower="-0.7" upper="0.7" effort="0" velocity="0" />
  </joint>
  <link name="phalanx_link2_int">
    <inertial>
      <origin xyz="0.0033404 0.00030416 -0.0057723" rpy="0 0 0" />
      <mass value="0.0057585" />
      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
    </inertial>
    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
  </link>
  <joint name="joint4_int" type="revolute">
    <origin xyz="0 0 -0.0114" rpy="0 0 0" />
    <parent link="phalanx_link1_int" />
    <child link="phalanx_link2_int" />
    <axis xyz="0 1 0" />
    <limit lower="-0.7" upper="0.7" effort="0" velocity="0" />
  </joint>
  <link name="phalanx_link3_int">
    <inertial>
      <origin xyz="9.7987E-05 -0.00025512 0.0076047" rpy="0 0 0" />
      <mass value="0.0019386" />
      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
    </inertial>
    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
  </link>
  <joint name="joint5_int" type="revolute">
    <origin xyz="0 0 -0.0114" rpy="3.1416 0 0" />
    <parent link="phalanx_link2_int" />
    <child link="phalanx_link3_int" />
    <axis xyz="0 1 0" />
    <limit lower="-0.7" upper="0.7" effort="0" velocity="0" />
  </joint>
  <link name="phalanx_link1_dis">
    <inertial>
      <origin xyz="-0.00010858 0.00025287 -0.0094074" rpy="0 0 0" />
      <mass value="0.0023104" />
      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
    </inertial>
    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
  </link>
  <joint name="joint6_dis" type="revolute">
    <origin xyz="0 0 0.0149" rpy="3.1416 0 0" />
    <parent link="phalanx_link3_int" />
    <child link="phalanx_link1_dis" />
    <axis xyz="0 1 0" />
    <limit lower="-0.7" upper="0.7" effort="0" velocity="0" />
  </joint>
</robot>

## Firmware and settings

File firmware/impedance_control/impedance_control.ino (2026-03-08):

#include <SimpleKalmanFilter.h>
#include "AS5600.h"

// Impedance control parameters
float K_initial = 6.5;     // Initial stiffness (N/degree)
float B_initial = 2.25;     // Initial damping (N·s/degree)
float I = 451.27 * 1e-9;   // Inertia (kg * m²), obtained from SolidWorks

// Desired values
float desired_angle = 90.0;      // Desired inital angle in degrees for home position(fully extended)
float desired_pressure = 200.0;  // Desired pressure in gram-force

// Kalman filter configurations for velocity, acceleration, and pressure
SimpleKalmanFilter kalman_velocity(1, 1, 0.01);       // Kalman filter for velocity
SimpleKalmanFilter kalman_acceleration(1, 1, 0.01);   // Kalman filter for acceleration
SimpleKalmanFilter kalman_pressure(1, 1, 0.01);       // Kalman filter for pressure

// Sampling period target (microseconds) — 10 ms = 100 Hz
const unsigned long CYCLE_PERIOD_US = 10000UL;

// dt in seconds — updated each cycle from actual elapsed time.
// Used by velocity and acceleration estimators for accuracy.
float dt = 0.01f;

// Use default Wire
AS5600 as5600;

// Output pins
#define PIN_OUTPUT_A 5
#define PIN_OUTPUT_B 6

// Pressure sensor calibration
double pressureSensorOffset = 0.0;

void setup() {
    Serial.begin(115200);
    configureEncoder();
    pressureSensorOffset = pressureSensorCalibration();
}

void loop() {
    // Cycle timer — micros() gives 1 µs resolution.
    // Declared static so it persists across calls and tracks the true
    // start of the previous cycle for accurate dt measurement.
    static unsigned long cycle_start_us = micros();

    // Read current angle and pressure from sensors
    float current_angle    = readAngleSensor();
    float current_pressure = readPressureSensor();
    float filtered_pressure = kalman_pressure.updateEstimate(current_pressure);

    // Update dt from actual elapsed time since the last cycle started.
    // This feeds the velocity/acceleration estimators with the real sample
    // interval instead of the assumed 10 ms, keeping kinematics accurate
    // even when Serial I/O or sensor reads vary in duration.
    dt = constrain((micros() - cycle_start_us) / 1e6f, 0.001f, 0.05f);

    // Read desired angle from Python pipeline over serial.
    // Falls back to last received value if no new data this cycle.
    desired_angle = readDesiredAngle();

    // Real-time adjustment of stiffness and damping (variable impedance control)
    float K = (abs(desired_angle - current_angle) > 5.0) ? K_initial : K_initial * 0.5;
    float B = (abs(kalman_velocity.updateEstimate(0)) > 0.1) ? B_initial : B_initial * 0.8;

    // Calculate position and pressure errors
    float position_error = desired_angle - current_angle;
    float pressure_error = desired_pressure - filtered_pressure;

    // Estimate angular velocity using the Kalman filter
    static float previous_angle = current_angle;
    float angular_velocity = (current_angle - previous_angle) / dt;
    float filtered_velocity = kalman_velocity.updateEstimate(angular_velocity);
    previous_angle = current_angle;

    // Estimate angular acceleration using the Kalman filter
    static float previous_velocity = filtered_velocity;
    float acceleration = (filtered_velocity - previous_velocity) / dt;
    float filtered_acceleration = kalman_acceleration.updateEstimate(acceleration);
    previous_velocity = filtered_velocity;

    // Impedance control law: τ = K(θd−θ) + B(−θ̇) + M(−θ̈) − Fc
    float stiffness_force = K * position_error;
    float damping_force   = B * (-filtered_velocity);
    float inertia_force   = I * (-filtered_acceleration);
    float control_torque  = constrain(
        (stiffness_force + damping_force + inertia_force - filtered_pressure),
        -255, 255
    );

    applyTorque(control_torque);

    // Send status back to Python pipeline (SerialBridge.read_status()).
    // Format: desired_angle, current_angle, pressure, torque, velocity, acceleration
    sendStatus(desired_angle, current_angle, filtered_pressure,
               control_torque, filtered_velocity, filtered_acceleration);

    // Dynamic delay — wait only the time remaining in the 10 ms period.
    // If the loop body took 2 ms, we wait 8 ms.
    // If it overran 10 ms (e.g. Serial stall), skip delay and continue.
    unsigned long elapsed_us = micros() - cycle_start_us;
    if (elapsed_us < CYCLE_PERIOD_US) {
        delayMicroseconds(CYCLE_PERIOD_US - elapsed_us);
    }

    // Reset cycle timer AFTER the delay so the next dt is exact.
    cycle_start_us = micros();
}

// Function to configure the encoder
void configureEncoder() {
    Serial.println(__FILE__);
    Serial.print("AS5600_LIB_VERSION: ");
    Serial.println(AS5600_LIB_VERSION);

    Wire.begin();
    as5600.begin(2);  // Set direction pin
    as5600.setDirection(AS5600_CLOCK_WISE);  // Set direction

    Serial.println(as5600.getAddress());
    Serial.print("Connect: ");
    Serial.println(as5600.isConnected());

    delay(1000);
}

// Function to read the angle sensor
float readAngleSensor() {
    return as5600.rawAngle() * AS5600_RAW_TO_DEGREES;
}

// Function to read the pressure sensor and apply Kalman filter
float readPressureSensor() {
    float voltage = fmap((analogRead(A0) - pressureSensorOffset), 0.0, 1023.0, 0.0, 5.0);
    float pressure = ((100 * voltage) / 0.165); // Pressure in Newtons
    return (pressure < 0) ? 0 : pressure;
}

// Calibration function for the pressure sensor
float pressureSensorCalibration() {
    float sum = 0;
    int samples = 30;
    for (int i = 0; i < samples; i++) {
        sum += analogRead(A0);
        delay(100);
    }
    Serial.print("Calibration done: ");
    Serial.println(sum / samples);
    return sum / samples;
}

// Mapping function for pressure sensor calibration
float fmap(float x, float a, float b, float c, float d) {
    return x / (b - a) * (d - c) + c;
}

// Function to apply torque to the actuator
void applyTorque(float torque) {
    if (torque >= 0) {
        // Move forward
        analogWrite(PIN_OUTPUT_A, abs(torque));  // Set motor forward with computed speed
        analogWrite(PIN_OUTPUT_B, 0);            // Stop reverse direction
    } else {
        // Move backward
        analogWrite(PIN_OUTPUT_A, 0);            // Stop forward direction
        analogWrite(PIN_OUTPUT_B, abs(torque));  // Set motor reverse with computed speed
    }
}


// =============================================================================
// SERIAL COMMUNICATION — swap these two functions to change transport layer
// =============================================================================

/*
 * readDesiredAngle()
 * Reads target angle from pipeline.py. Holds last value between updates.
 * Format: "<float>\n"  e.g. "142.50\n"
 * To revert to potentiometer: uncomment the analogRead line.
 */
float readDesiredAngle() {
    static float last_desired = desired_angle;
    if (Serial.available() > 0) {
        String line = Serial.readStringUntil('\n');
        line.trim();
        float received = line.toFloat();
        if (received >= 0.0 && received <= 360.0) {
            last_desired = received;
        }
    }
    // Potentiometer fallback — uncomment to use manual control:
    // last_desired = map(analogRead(A1), 0, 1023, 70, 288);
    return last_desired;
}

/*
 * sendStatus()
 * Sends controller state to Python pipeline each cycle via serial.
 * CSV format: desired_angle, current_angle, pressure, torque, velocity, accel
 * Match with SerialBridge.read_status() in predict.py if you add fields.
 */
void sendStatus(float d_angle, float c_angle, float pressure,
                float torque,  float velocity, float accel) {
    Serial.print(d_angle,  2); Serial.print(",");
    Serial.print(c_angle,  2); Serial.print(",");
    Serial.print(pressure, 2); Serial.print(",");
    Serial.print(torque,   2); Serial.print(",");
    Serial.print(velocity, 4); Serial.print(",");
    Serial.println(accel,  4);
}

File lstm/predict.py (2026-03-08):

"""
predict.py
==========
Stage 2 and 3 of 3 in the grasping pipeline.

    [1] grasp_point_generator.py  ->  (x, y) contact point
    [2] LSTMPredictor             ->  theta motor angle      <- THIS FILE
    [3] SerialBridge              ->  Arduino serial         <- THIS FILE

Usage as module (called by pipeline.py):
    from predict import LSTMPredictor, SerialBridge

Usage standalone (no hardware):
    python predict.py --dry-run --x 22.0 --y -37.0

Usage with hardware:
    python predict.py --port COM5 --x 22.0 --y -37.0
"""

import os
import time
import argparse
import numpy as np
import torch
import torch.nn as nn
from typing import Optional

try:
    import serial
    SERIAL_AVAILABLE = True
except ImportError:
    SERIAL_AVAILABLE = False


# ---------------------------------------------------------------------------
# Model — single definition shared with train.py
# ---------------------------------------------------------------------------

class LSTMInverseKinematics(nn.Module):
    """
    LSTM inverse kinematics observer for the UMoBIC-Finger.
    Maps fingertip (x, y) in mm to motor pulley angle theta in degrees.
    Trained on ArUco motion capture data. R2 = 0.9998.
    """

    def __init__(self, input_size: int = 2,
                 hidden_size: int = 64,
                 output_size: int = 1):
        super().__init__()
        self.hidden_size = hidden_size
        self.lstm = nn.LSTM(input_size, hidden_size, batch_first=True)
        self.fc   = nn.Linear(hidden_size, output_size)

    def forward(self, x: torch.Tensor) -> torch.Tensor:
        h0 = torch.zeros(1, x.size(0), self.hidden_size, device=x.device)
        c0 = torch.zeros(1, x.size(0), self.hidden_size, device=x.device)
        out, _ = self.lstm(x, (h0, c0))
        return self.fc(out[:, -1, :])


# ---------------------------------------------------------------------------
# Stage 2 — LSTM Predictor
# ---------------------------------------------------------------------------

class LSTMPredictor:
    """
    Loads pretrained LSTM weights and runs inference.

    Args:
        weights_path: Path to .pth file.
        device:       'cpu' or 'cuda'. Auto-detected if not given.
    """

    def __init__(self, weights_path: str, device: Optional[str] = None):
        self.device = device or ("cuda" if torch.cuda.is_available() else "cpu")
        self.model  = LSTMInverseKinematics()
        self.model.load_state_dict(torch.load(weights_path, map_location=self.device))
        self.model.to(self.device)
        self.model.eval()
        print(f"[LSTMPredictor] Loaded '{os.path.basename(weights_path)}' on {self.device}")

    def predict(self, x: float, y: float) -> float:
        """
        Predict motor angle for one fingertip position.

        Args:
            x: Fingertip x in mm (palm frame, ArUco calibrated).
            y: Fingertip y in mm.

        Returns:
            theta: Motor pulley angle in degrees.
        """
        inp = torch.tensor([[[x, y]]], dtype=torch.float32, device=self.device)
        with torch.no_grad():
            return float(self.model(inp).item())

    def predict_batch(self, points: np.ndarray) -> np.ndarray:
        """
        Predict angles for multiple (x, y) points.
        points: (N, 2) array. Returns (N,) array of degrees.
        """
        inp = torch.tensor(points, dtype=torch.float32, device=self.device).unsqueeze(1)
        with torch.no_grad():
            return self.model(inp).cpu().numpy().flatten()


# ---------------------------------------------------------------------------
# Stage 3 — Serial Bridge
# Swap this class to change transport layer (ROS, socket, CAN).
# pipeline.py only calls send_angle() and read_status().
# ---------------------------------------------------------------------------

class SerialBridge:
    """
    Sends motor angle to the Arduino impedance controller over USB serial.

    Protocol:
        Python -> Arduino:  "<angle>\n"           e.g. "142.50\n"
        Arduino -> Python:  comma-separated CSV   e.g. "142.50,138.2,0.3,87.1,2.1,0.04"
                            fields: desired, current, pressure, torque, velocity, accel

    Args:
        port:     'COM5' on Windows, '/dev/ttyUSB0' on Linux/Mac.
        baudrate: Must match Serial.begin() in the .ino file. Default 115200.
        timeout:  Read timeout in seconds. Default 0.1.
    """

    def __init__(self, port: str, baudrate: int = 115200, timeout: float = 0.1):
        if not SERIAL_AVAILABLE:
            raise ImportError("pyserial not installed. Run: pip install pyserial")
        self.port     = port
        self.baudrate = baudrate
        self.timeout  = timeout
        self._ser: Optional[serial.Serial] = None

    def connect(self) -> None:
        """Open serial port. Waits 2 s for Arduino hardware reset on connect."""
        self._ser = serial.Serial(self.port, self.baudrate, timeout=self.timeout)
        time.sleep(2.0)
        print(f"[SerialBridge] Connected  {self.port}  @ {self.baudrate} baud")

    def disconnect(self) -> None:
        """Close serial port."""
        if self._ser and self._ser.is_open:
            self._ser.close()
            print("[SerialBridge] Disconnected")

    def send_angle(self, angle: float) -> None:
        """
        Send target motor angle to the Arduino.
        The firmware reads this in readDesiredAngle() each loop cycle.

        Args:
            angle: Motor pulley target in degrees (range 0-360).
        """
        if self._ser is None or not self._ser.is_open:
            raise RuntimeError("[SerialBridge] Not connected. Call connect() first.")
        self._ser.write(f"{angle:.2f}\n".encode("utf-8"))

    def read_status(self) -> Optional[str]:
        """
        Read one status line from Arduino (non-blocking).
        Returns comma-separated string or None if no data.
        """
        if self._ser and self._ser.in_waiting > 0:
            try:
                return self._ser.readline().decode("utf-8").strip()
            except Exception:
                return None
        return None

    def __enter__(self):
        self.connect()
        return self

    def __exit__(self, *_):
        self.disconnect()


# ---------------------------------------------------------------------------
# Standalone entry point
# ---------------------------------------------------------------------------

_HERE         = os.path.dirname(os.path.abspath(__file__))
_WEIGHTS_PATH = os.path.join(_HERE, "lstm", "weights", "lstm_inverse_kinematics.pth")
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

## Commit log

2026-03-08 cad files
    [bavel_gear_pinion.STL, bavel_gear_pulley.STL, bavel_gear_pulley_thumb.STL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]
2026-03-08 finger trajectory dataset
    [finger_trajectory_dataset.csv, test_data.csv, train_data.csv]
2026-03-08 kinematics calculation and simulation
    [finger_trajectory.csv]
2026-03-08 lstm nn inverse kinematics
2026-03-08 motion capture finger trajectory data collection
2026-03-08 mujoco simulation env
    [finger_mujoco.csv, finger_mujoco.urdf, mjmodel.xml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]

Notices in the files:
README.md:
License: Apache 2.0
